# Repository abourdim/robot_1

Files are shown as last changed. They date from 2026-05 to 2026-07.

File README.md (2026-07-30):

# 🤖 esp32c3_super_mini_robot — ESP32-C3 RISC-V Robot

ESP32-C3 robot project — Arduino/PlatformIO firmware, browser-based flasher and monitor, audit dashboard, and a 9-theme Workshop-DIY web UI.

## 🌐 Live site

**[abourdim.github.io/esp32c3_super_mini_robot](https://abourdim.github.io/esp32c3_super_mini_robot/)** — auto-deployed from `01_software/01_app/02_web/` on every push.

### 📚 Guides — by audience

| Guide | For | What it covers |
|---|---|---|
| [`user-guide.html`](https://abourdim.github.io/esp32c3_super_mini_robot/user-guide.html) | 🦸 Kids · end users | Power on · pair phone · drive · light/sound meanings · troubleshooting · safety |
| [`build-guide.html`](https://abourdim.github.io/esp32c3_super_mini_robot/build-guide.html) | 🔧 Makers | BOM (~$30–45) · tools · wiring · step-by-step assembly · 3D parts · first flash |
| [`start-here.html`](https://abourdim.github.io/esp32c3_super_mini_robot/start-here.html) | 💻 Developers | Firmware narrative tour. 14 missions: layout, build, flash, debug. |
| [`learn.html`](https://abourdim.github.io/esp32c3_super_mini_robot/learn.html) | 🧠 Curious devs | Reference manual. Every `launch.sh` option · `platformio.ini` directive · RMT · partition table · addr2line · Web Serial. |
| [`hardware.html`](https://abourdim.github.io/esp32c3_super_mini_robot/hardware.html) | ⚡ Hardware hackers | Live PCB browser. 5-layer toggle · GPIO pin map · connector reference · links to KiCad source + gerbers + interactive BOM. |
| [`instructor.html`](https://abourdim.github.io/esp32c3_super_mini_robot/instructor.html) | 🧑‍🏫 Teachers | Prereqs · 90-min lesson plan · student FAQ · cheat sheet · reset checklist |

### 🛠️ Tools — runs in your browser

| Tool | What it does |
|---|---|
| [`flash.html`](https://abourdim.github.io/esp32c3_super_mini_robot/flash.html) | Click-to-flash via Web Serial (Chrome/Edge) |
| [`monitor.html`](https://abourdim.github.io/esp32c3_super_mini_robot/monitor.html) | Live serial monitor in the browser |
| [`audit.html`](https://abourdim.github.io/esp32c3_super_mini_robot/audit.html) | Bug tracker · severity dashboard · BUG-NNN forensics |
| [`index.html`](https://abourdim.github.io/esp32c3_super_mini_robot/) | Launcher landing page |

## 📁 Structure

```
esp32c3_super_mini_robot/
├── 01_software/
│   ├── 01_app/                  ⚙ main robot firmware (ESP32-C3 Arduino)
│   │   ├── 01_src/              source files (one .h/.cpp pair per system)
│   │   ├── 02_web/              browser tools (canonical Pages source)
│   │   ├── platformio.ini       build orders (pinned platform & libs)
│   │   └── launch.sh            interactive launcher menu
│   ├── 02_calibration/          calibration sketch
│   ├── 03_demo/                 demo project
│   ├── 05_bare_minimum/         minimal sketch
│   └── 4_wled/                  vendored WLED source
├── 02_hardware/                 (PCB design — TBD)
└── 03_3d/                       (3D-print files — TBD)
```

## 🚀 Quick start

```bash
cd 01_software/01_app
./launch.sh                    # interactive menu (option 0 = full setup)
./launch.sh flash              # one-shot: compile + upload + monitor
```

Everything else is documented inside the launcher menu and in the live site's [Start Here](https://abourdim.github.io/esp32c3_super_mini_robot/start-here.html) guide.

## 🎨 Themes

The web tools ship with **9 themes in 4 audience-mood groups**:

- 🔬 **Science** — `lab-light` · `lab-dark`
- 💻 **Hacker** — `terminal` · `solarized`
- 🤖 **Pro** — `robot` (default)
- 🦸 **Kids action** — `bot-pop` · `kapow` · `blastoff` · `dino`

Switch in **Settings (⚙️)** in any tool. Plus 3 languages (EN/FR/AR with RTL).

## 🐛 Known bugs

See [`audit.html`](https://abourdim.github.io/esp32c3_super_mini_robot/audit.html) for the live tracker. Headline incidents documented:
- **BUG-001** — RMT ISR recursion crash on ESP32-C3 (✅ fixed by pinning to ESP-IDF 5.1)
- **BUG-002** — Ctrl+C in MSYS2 monitor (🔍 open)
- **BUG-003** — Unpinned platform → non-reproducible builds (✅ fixed)
- **BUG-004** — RemoteXY "No PRO license" (🔍 open — UI exceeds free 5-var quota)
- **BUG-005** — Native USB CDC reset race during esptool upload (🔍 open)

## 📜 License

Vendored WLED is MIT — see `01_software/4_wled/WLED/LICENSE`. Project code: license TBD.

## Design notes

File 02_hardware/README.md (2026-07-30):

# 🔌 Hardware

KiCad source, PCB renders, BOMs, and gerbers for the Robot-01 board.

## Versions

| Version | Date | Status | Folder |
|---|---|---|---|
| **v3** | June–July 2025 | ✅ **Current — schematic source of truth** | [`v3/`](v3/) |
| v2 | May–June 2025 | 🔒 Archived | [`v2/`](v2/) |
| v1 | Aug 2025 (1st batch) | 🔒 Archived | [`v1/`](v1/) |

## Live browser

The current version is also rendered as a layered SVG viewer on the website:
**[abourdim.github.io/esp32c3_super_mini_robot/hardware.html](https://abourdim.github.io/esp32c3_super_mini_robot/hardware.html)** — toggle layers, zoom, link to source.

## v3 contents

```
v3/
├── 37_rich_light_move_v3.kicad_sch      ← schematic (S-expressions, text)
├── 37_rich_light_move_v3.kicad_pcb      ← PCB layout
├── 37_rich_light_move_v3.kicad_pro      ← KiCad project file
├── 37_rich_light_move_v3-F_Cu.svg       ← front copper render
├── 37_rich_light_move_v3-B_Cu.svg       ← back copper render
├── 37_rich_light_move_v3-F_Silkscreen.svg
├── 37_rich_light_move_v3-F_Courtyard.svg
├── 37_rich_light_move_v3-Edge_Cuts.svg
├── 00_lcsc/                             ← LCSC parts BOMs
├── bom/ibom.html                        ← interactive BOM (KiCad InteractiveHtmlBom)
└── production/                          ← gerbers + CSVs for fab
    ├── 37_richa_light_move_v3.zip       ← gerbers (send to PCBWay/JLCPCB)
    ├── bom.csv
    ├── designators.csv
    ├── netlist.ipc
    └── positions.csv
```

## Top-level BOM files

`bom_lcsc.xls`, `bom_jlcpcb2.xls`, `bom_assembly_jlcpcb_21062025.xls` — alternate BOM exports for different fab houses.

## Auto-backups (gitignored)

KiCad creates `*-backups/` folders with timestamped zips on every save.
These are **not tracked** — see project root `.gitignore`. Real source is in
the `.kicad_sch` / `.kicad_pcb` files themselves.

## Datasheet

`2410121311_S-S-SFN-1407PA7-6_C360603.pdf` — datasheet for one of the
LCSC parts used in the build (component lookup by C-number).

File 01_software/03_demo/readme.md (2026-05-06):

/c/Users/Win10/.platformio/packages/tool-esptoolpy/esptool.py --chip esp32c3 --port COM15  erase_flash

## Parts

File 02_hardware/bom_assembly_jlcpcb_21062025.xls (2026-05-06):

Comment | Designator | Footprint | JLCPCB Part #
1k | R1,R3,R8 | 0805 | C17513
4K7 | R4,R9 | 0805 | C17673
Conn_01x04_Pin | J6 | PinHeader_1x04_P2.54mm_Vertical | C2718488
AMS1117-5.0 | U4 | SOT-223-3_TabPin2 | C6187
100nF | C1,C2,C3,C4,C5,C6 | 0805 | C49678
TB6612FNG | U1 | SSOP-24_5.3x8.2mm_P0.65mm | C88224
SK12D07VG4 | U2 | SK12D07VG4 | C393937
blue | D8 | 0805 | C2293
led_tx1812cxa_5050 | D1,D2,D3,D4 | led_tx1812cxa_5050 | C784550
10K | R10,R11,R2,R5,R6,R7 | 0805 | C17414
green | D5 | 0805 | C2297
SW_Omron_B3FS | SW1 | SW_Push_1P1T_NO_6x6mm_H9.5mm | C5143662
Screw_Terminal_01x02 | J1,J11,J7,J8,J9 | TerminalBlock_Phoenix_MPT-0,5-2-2.54_1x02_P2.54mm_Horizontal | C2922597
green | D7,D6 | LED_D3.0mm | C85160
Conn_01x03_Pin | J2,J3,J4,J5 | PinHeader_1x03_P2.54mm_Vertical | C2937625
BUZZER | BZ2 | Buzzer_TDK_PS1240P02BT_D12.2mm_H6.5mm | C360603

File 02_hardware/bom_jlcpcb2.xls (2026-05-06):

Comment | Designator | Footprint | JLCPCB Part #
1k | R1,R13,R2,R3,R4 | 0805 | C17513
4K7 | R14,R7 | 0805 | C17673
AMS1117-5.0 | U3 | SOT-223-3_TabPin2 | C6187
100nF | C1,C2,C3,C4 | 0805 | C49678
SK12D07VG4 | U1 | SK12D07VG4 | C393937
led_tx1812cxa_5050 | D10,D11,D12,D9 | led_tx1812cxa_5050 | C784550
10K | R10,R11,R12,R5,R6,R8,R9 | 0805 | C17414
yellow | D3,D4 | 0805 | C2296
green | D5 | 0805 | C2297
SW_Omron_B3FS | SW1 | SW_Push_1P1T_NO_6x6mm_H9.5mm | C5143662
2N7002 | Q1,Q2 | SOT-23_Handsoldering | C8545
1N4007 | D1,D2 | D_SOD-123F | C2892681
Conn_01x03_Pin | J4,J5,J6,J7,J8,J9 | PinHeader_1x03_P2.54mm_Vertical | C2937625

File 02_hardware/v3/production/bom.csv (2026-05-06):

Designator | Footprint | Quantity | Value | LCSC Part #
BB1 | oled_128X64_no_holes | 1 | oled_128x32
BZ1 | buzz_8x14 | 1 | buzz_8x14
BZ2 | Buzzer_TDK_PS1240P02BT_D12.2mm_H6.5mm | 1 | BUZZER
C1, C2, C3, C4, C5, C6 | 0805 | 6 | 100nF
D1, D2, D3, D4 | led_tx1812cxa_5050 | 4 | led_tx1812cxa_5050
D5 | 0805 | 1 | green
D6 | LED_D3.0mm | 1 | green
D7 | LED_D3.0mm | 1 | blue
D8 | 0805 | 1 | blue
H1 | MountingHole_3.2mm_M3_Pad_Via | 1 | MountingHole
J1, J11, J7, J8, J9 | TerminalBlock_Phoenix_MPT-0,5-2-2.54_1x02_P2.54mm_Horizontal | 5 | Screw_Terminal_01x02
J10 | JST_PH_S2B-PH-K_1x02_P2.00mm_Horizontal | 1 | Conn_01x02_Pin
J2, J3, J4, J5 | PinHeader_1x03_P2.54mm_Vertical | 4 | Conn_01x03_Pin
J6 | PinHeader_1x04_P2.54mm_Vertical | 1 | Conn_01x04_Pin
JP1, JP2 | SolderJumper-2_P1.3mm_Open_TrianglePad1.0x1.5mm | 2 | SolderJumper_2_Open
R1, R3, R8 | 0805 | 3 | 1k
R10, R11, R2, R5, R6, R7 | 0805 | 6 | 10K
R4, R9 | 0805 | 2 | 4K7
SW1 | SW_Push_1P1T_NO_6x6mm_H9.5mm | 1 | SW_Omron_B3FS
U1 | SSOP-24_5.3x8.2mm_P0.65mm | 1 | TB6612FNG
U2 | SK12D07VG4 | 1 | SK12D07VG4
U3 | MODULE_ESP32-C3_SUPERMINI | 1 | ESP32-C3_SUPERMINI
U4 | SOT-223-3_TabPin2 | 1 | AMS1117-5.0

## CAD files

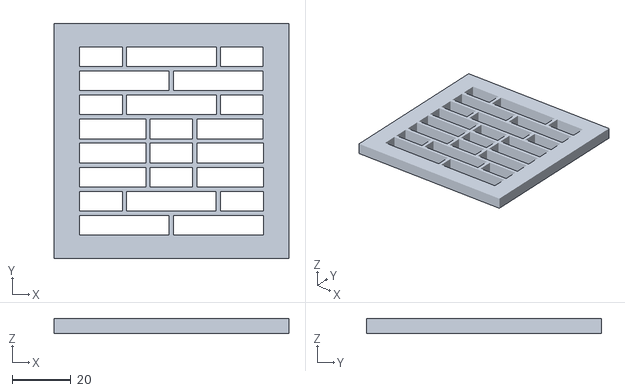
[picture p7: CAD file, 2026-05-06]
01_software/4_wled/WLED/usermods/word-clock-matrix/Word Clock Baffle.stl
80.0 x 80.0 x 5.00

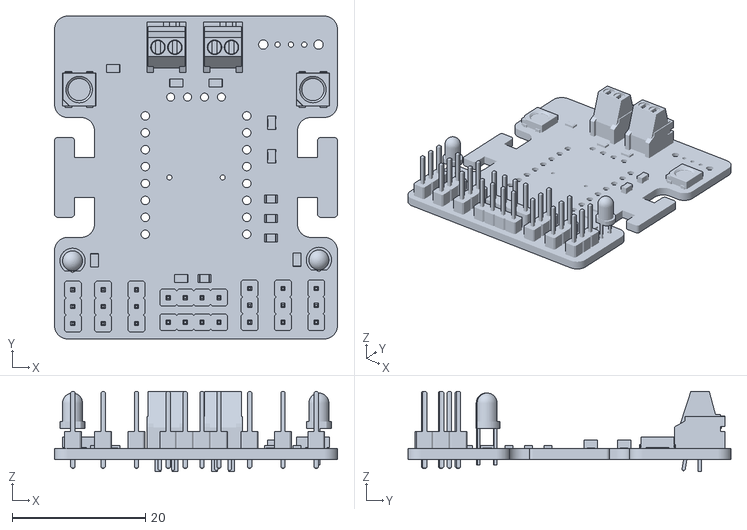
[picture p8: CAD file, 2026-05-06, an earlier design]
02_hardware/v1/1.stl
42.5 x 48.5 x 12.0

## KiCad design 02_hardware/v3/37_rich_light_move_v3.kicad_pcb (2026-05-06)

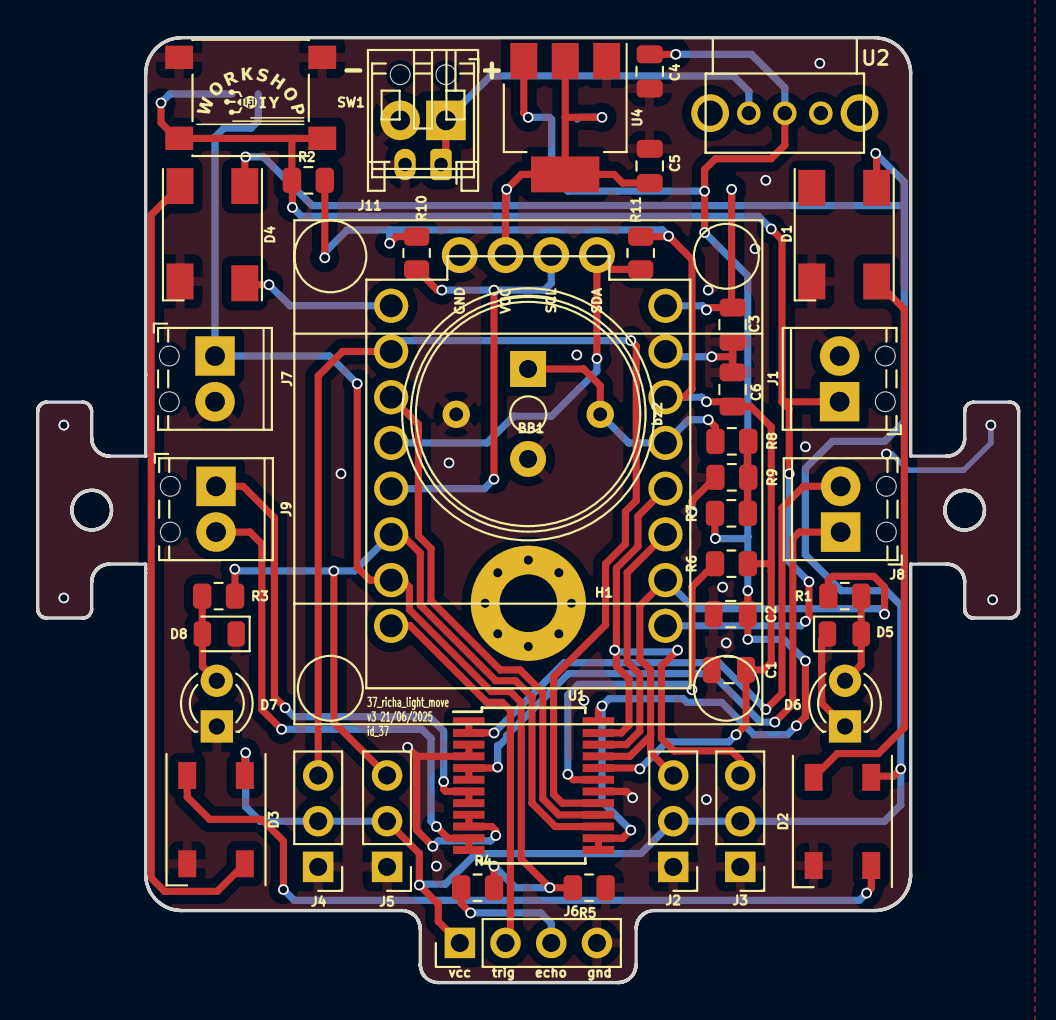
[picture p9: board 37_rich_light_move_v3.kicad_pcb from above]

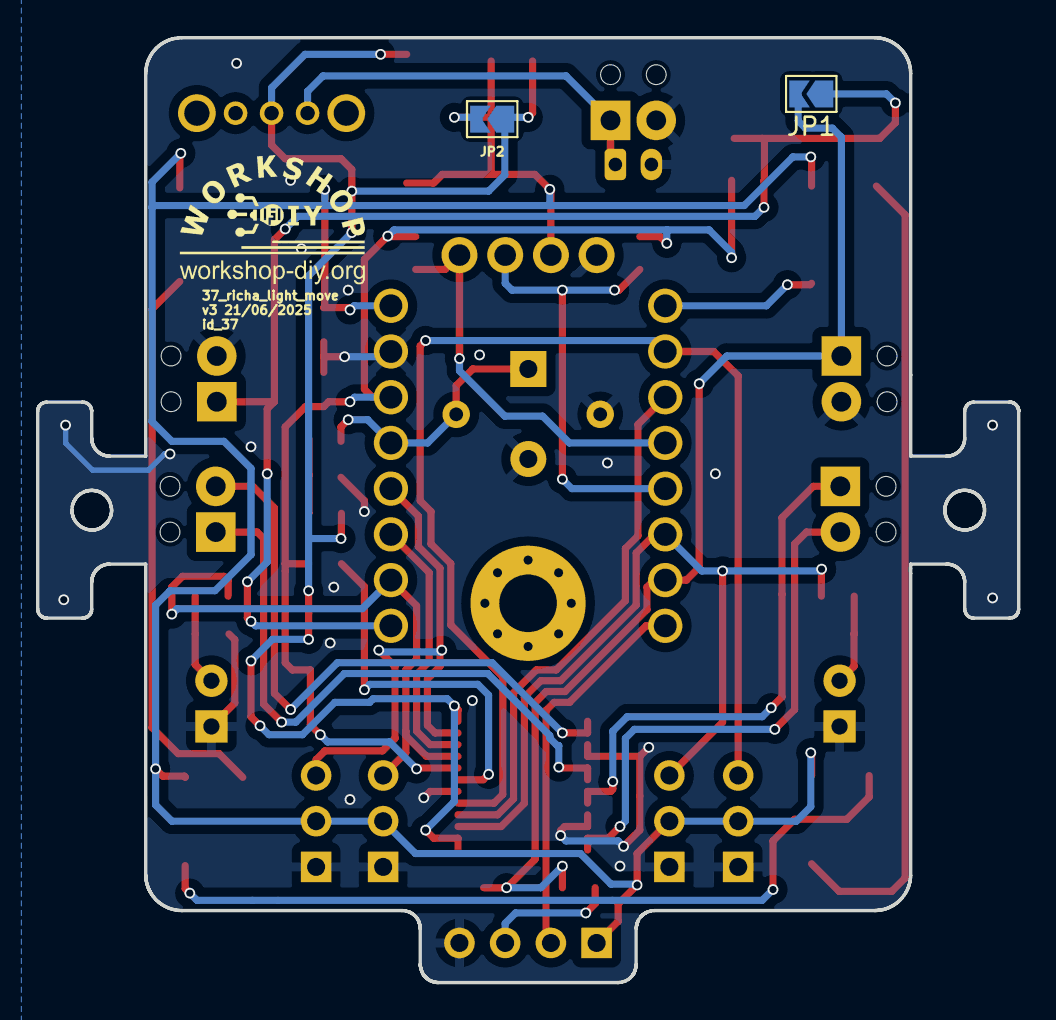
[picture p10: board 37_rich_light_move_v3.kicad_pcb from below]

Board: 2 copper layers, 54.5 x 52.5 mm, 47 parts (2 on the bottom side), 30 nets.

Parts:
BB1: oled_128x32; oled_128X64_no_holes
C1, C2, C3, C4, C5, C6: 100nF; C_0805_2012Metric
D1, D2, D3, D4: led_tx1812cxa_5050
D5: green; LED_0805_2012Metric
D6: green; LED_D3.0mm
D7: blue; LED_D3.0mm
D8: blue; LED_0805_2012Metric
H1: MountingHole; MountingHole_3.2mm_M3_Pad_Via
J1, J7, J8, J9, J11: Screw_Terminal_01x02; TerminalBlock_Phoenix_MPT-0,5-2-2.54_1x02_P2.54mm_Horizontal
J2, J3, J4, J5: Conn_01x03_Pin; PinHeader_1x03_P2.54mm_Vertical
J6: Conn_01x04_Pin; PinHeader_1x04_P2.54mm_Vertical
J10: Conn_01x02_Pin; JST_PH_S2B-PH-K_1x02_P2.00mm_Horizontal
JP1, JP2: SolderJumper_2_Open; SolderJumper-2_P1.3mm_Open_TrianglePad1.0x1.5mm
R1, R3, R8: 1k; R_0805_2012Metric
R2, R6, R7: 10k; R_0805_2012Metric
R4, R9: 4K7; R_0805_2012Metric
R5, R10, R11: 10K; R_0805_2012Metric
SW1: SW_Omron_B3FS; SW_Push_1P1T_NO_6x6mm_H9.5mm
U1: TB6612FNG; SSOP-24_5.3x8.2mm_P0.65mm
U2: SK12D07VG4
U3: ESP32-C3_SUPERMINI; MODULE_ESP32-C3_SUPERMINI
U4: AMS1117-5.0; SOT-223-3_TabPin2
bz1: buzz_8x14
bz2: BUZZER; Buzzer_TDK_PS1240P02BT_D12.2mm_H6.5mm

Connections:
3V3: C1.1, C6.1, R2.1, R6.1, R10.1, R11.1, U1.20 (VCC), U3.3.3 (3V3)
5V: BB1.2 (VCC), C3.1, C5.1, D1.1 (VDD), D2.1 (VDD), D3.1 (VDD), D4.1 (VDD), J2.2, J3.2, J4.2, J5.2, J6.1, JP2.2 (B), U3.5V, U4.2 (VO)
GND: BB1.1 (GND), C1.2, C2.2, C3.2, C4.2, C5.2, C6.2, D1.3 (GND), D2.3 (GND), D3.3 (GND), D4.3 (GND), D5.1 (K), D6.1 (K), D7.1 (K), D8.1 (K), J1.2, J2.1, J3.1, J4.1, J5.1, J6.4, J7.2, J10.2, J11.2, R5.2, R9.2, SW1.2, U1.3 (PGND1), U1.4 (PGND1), U1.9 (PGND2), U1.10 (PGND2), U1.18 (GND), U3.G (GND), U4.1 (GND), bz1.1, bz2.2 (GND)
unnamed: D1.4 (DIN), D2.2 (DOUT)
unnamed: D2.4 (DIN), D3.2 (DOUT)
unnamed: D3.4 (DIN), D4.2 (DOUT)
unnamed: D5.2 (A), D6.2 (A), R1.2
unnamed: D7.2 (A), D8.2 (A), R3.2
unnamed: J6.3, R4.1
unnamed: J8.1, U1.5 (AO2), U1.6 (AO2)
unnamed: J8.2, U1.1 (AO1), U1.2 (AO1)
unnamed: J9.1, U1.7 (BO2), U1.8 (BO2)
unnamed: J9.2, U1.11 (BO1), U1.12 (BO1)
unnamed: R7.2, R8.1, R9.1
unnamed: R6.2, U1.19 (STBY)
VCC: C2.1, C4.1, JP2.1 (A), R7.1, U1.13 (VM2), U1.14 (VM3), U1.24 (VM1), U2.COM, U4.3 (VI)
VDDA: J10.1, J11.1, U2.2
gpio_00: J1.1, JP1.1 (A), R2.2, SW1.1, U3.0 (GPIO0)
gpio_01: J2.3, R1.1, U1.21 (AIN1), U3.1 (GPIO1)
gpio_02: U1.22 (AIN2), U3.2 (GPIO2)
gpio_03: J3.3, U1.23 (PWMA), U3.3 (GPIO3)
gpio_04: R8.2, U3.4 (GPIO4), bz1.2, bz2.1 (POS)
gpio_05: D4.4 (DIN), U3.5 (GPIO5)
gpio_06: J4.3, U1.17 (BIN1), U3.6 (GPIO6)
gpio_07: U1.16 (BIN2), U3.7 (GPIO7)
gpio_08: BB1.4 (SDA), R11.2, U3.8 (GPIO8)
gpio_09: BB1.3 (SCL), R10.2, U3.9 (GPIO9)
gpio_10: J5.3, R3.1, U1.15 (PWMB), U3.10 (GPIO10)
gpio_20: J7.1, JP1.2 (B), R4.2, R5.1, U3.20 (GPIO20)
gpio_21: J6.2, U3.21 (GPIO21)

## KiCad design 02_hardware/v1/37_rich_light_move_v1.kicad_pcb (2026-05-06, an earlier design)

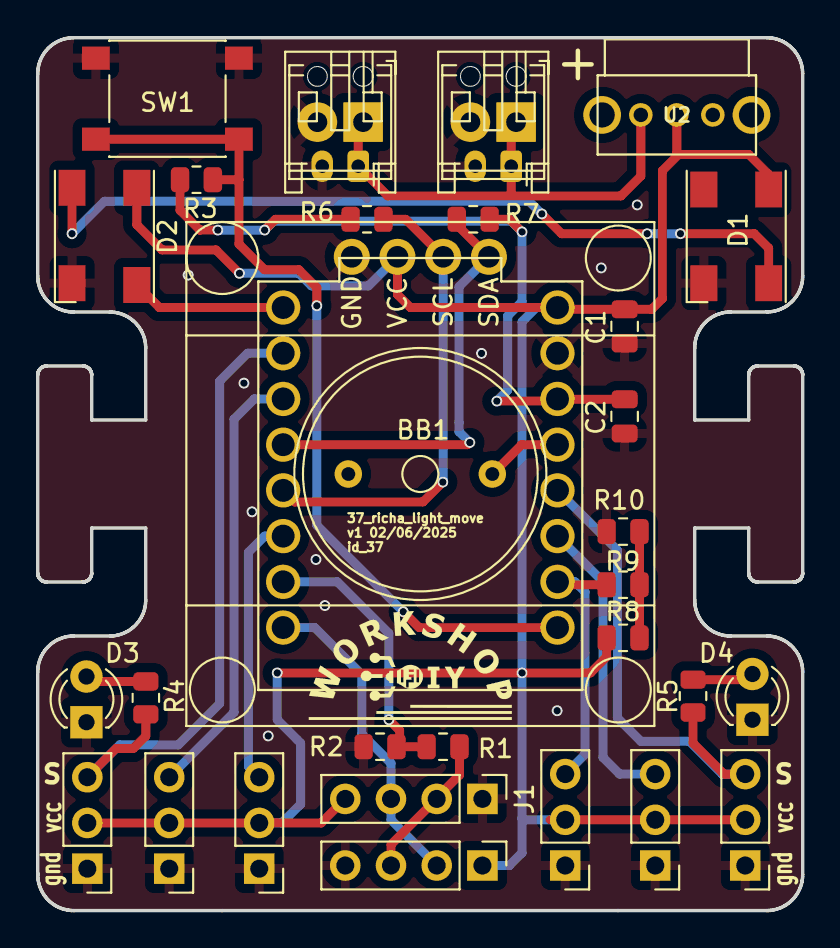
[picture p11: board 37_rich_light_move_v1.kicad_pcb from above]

Board: 2 copper layers, 42.5 x 48.5 mm, 33 parts (0 on the bottom side), 22 nets.

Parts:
BB1: oled_128x32; oled_128X64_no_holes
C1, C2: 100nF; C_0805_2012Metric
D1, D2: led_tx1812cxa_5050
D3, D4: yellow; LED_D3.0mm
J1, J2: Conn_01x04_Pin; PinHeader_1x04_P2.54mm_Vertical
J3, J4, J5, J6, J7, J8: Conn_01x03_Pin; PinHeader_1x03_P2.54mm_Vertical
J9, J10: Conn_01x02_Pin; JST_PH_S2B-PH-K_1x02_P2.00mm_Horizontal
J11, J12: Screw_Terminal_01x02; TerminalBlock_Phoenix_MPT-0,5-2-2.54_1x02_P2.54mm_Horizontal
R1: 4K7; R_0805_2012Metric
R2, R6, R7: 10K; R_0805_2012Metric
R3, R8, R10: 10k; R_0805_2012Metric
R4, R5, R9: 1k; R_0805_2012Metric
SW1: SW_Omron_B3FS; SW_Push_1P1T_NO_6x6mm_H9.5mm
U1: ESP32-C3_SUPERMINI; MODULE_ESP32-C3_SUPERMINI
U2: SK12D07VG4
bz1: buzz_8x14

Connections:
3V3: C2.1, R3.1, R6.1, R7.1, U1.3.3 (3V3)
GND: BB1.1 (GND), C1.2, C2.2, D1.3 (GND), D2.3 (GND), D3.1 (K), D4.1 (K), J1.1, J2.4, J3.1, J4.1, J5.1, J6.1, J7.1, J8.1, J9.2, J10.2, J11.2, J12.2, R2.2, R10.2, SW1.2, U1.G (GND), bz1.1
unnamed: D1.4 (DIN), D2.2 (DOUT)
unnamed: D3.2 (A), R4.2
unnamed: D4.2 (A), R5.2
unnamed: J1.2, J2.3, R1.1
unnamed: R8.2, R9.1, R10.1
VCC: BB1.2 (VCC), C1.1, D1.1 (VDD), D2.1 (VDD), J1.4, J2.1, J3.2, J4.2, J5.2, J6.2, J7.2, J8.2, R8.1, U1.5V, U2.COM
VDDA: J9.1, J10.1, J11.1, J12.1, U2.2
gpio_00: R3.2, SW1.1, U1.0 (GPIO0)
gpio_01: J7.3, R9.2, U1.1 (GPIO1)
gpio_02: J3.3, U1.2 (GPIO2)
gpio_03: J8.3, R5.1, U1.3 (GPIO3)
gpio_04: U1.4 (GPIO4), bz1.2
gpio_05: D2.4 (DIN), U1.5 (GPIO5)
gpio_06: J4.3, R4.1, U1.6 (GPIO6)
gpio_07: J5.3, U1.7 (GPIO7)
gpio_08: BB1.4 (SDA), R7.2, U1.8 (GPIO8)
gpio_09: BB1.3 (SCL), R6.2, U1.9 (GPIO9)
gpio_10: J6.3, U1.10 (GPIO10)
gpio_20: R1.2, R2.1, U1.20 (GPIO20)
gpio_21: J1.3, J2.2, U1.21 (GPIO21)

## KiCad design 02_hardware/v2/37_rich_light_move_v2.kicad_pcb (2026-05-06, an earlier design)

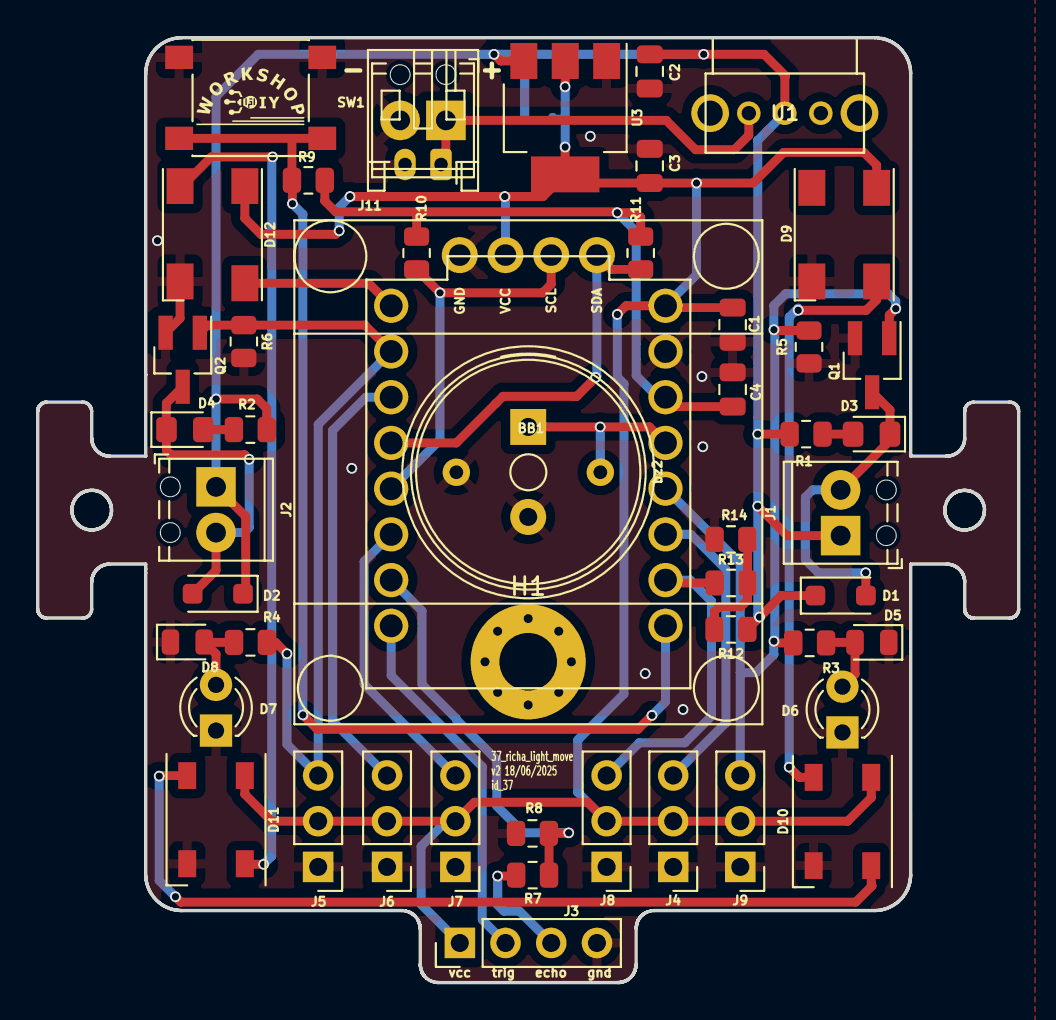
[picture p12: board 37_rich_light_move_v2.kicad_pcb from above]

Board: 2 copper layers, 54.5 x 52.5 mm, 52 parts (1 on the bottom side), 29 nets.

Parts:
BB1: oled_128x32; oled_128X64_no_holes
C1, C2, C3, C4: 100nF; C_0805_2012Metric
D1, D2: 1N4007; D_SOD-123F
D3, D4: yellow; LED_0805_2012Metric_Pad1.15x1.40mm_HandSolder
D5: green; LED_0805_2012Metric
D6: green; LED_D3.0mm
D7: blue; LED_D3.0mm
D8: blue; LED_0805_2012Metric
D9, D10, D11, D12: led_tx1812cxa_5050
H1: MountingHole; MountingHole_3.2mm_M3_Pad_Via
J1, J2, J11: Screw_Terminal_01x02; TerminalBlock_Phoenix_MPT-0,5-2-2.54_1x02_P2.54mm_Horizontal
J3: Conn_01x04_Pin; PinHeader_1x04_P2.54mm_Vertical
J4, J5, J6, J7, J8, J9: Conn_01x03_Pin; PinHeader_1x03_P2.54mm_Vertical
J10: Conn_01x02_Pin; JST_PH_S2B-PH-K_1x02_P2.00mm_Horizontal
JP1: SolderJumper_2_Open; SolderJumper-2_P1.3mm_Open_TrianglePad1.0x1.5mm
Q1, Q2: 2N7002; SOT-23_Handsoldering
R1, R2, R3, R4, R13: 1k; R_0805_2012Metric
R5, R6, R9, R12: 10k; R_0805_2012Metric
R7, R14: 4K7; R_0805_2012Metric
R8, R10, R11: 10K; R_0805_2012Metric
SW1: SW_Omron_B3FS; SW_Push_1P1T_NO_6x6mm_H9.5mm
U1: SK12D07VG4
U2: ESP32-C3_SUPERMINI; MODULE_ESP32-C3_SUPERMINI
U3: AMS1117-5.0; SOT-223-3_TabPin2
bz1: buzz_8x14
bz2: BUZZER; Buzzer_TDK_PS1240P02BT_D12.2mm_H6.5mm

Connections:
3V3: C4.1, R9.1, R10.1, R11.1, U2.3.3 (3V3)
5V: BB1.2 (VCC), C1.1, C3.1, D9.1 (VDD), D10.1 (VDD), D11.1 (VDD), D12.1 (VDD), J3.1, J4.2, J5.2, J6.2, J7.2, J8.2, J9.2, JP1.2 (B), U2.5V, U3.2 (VO)
GND: BB1.1 (GND), C1.2, C2.2, C3.2, C4.2, D5.1 (K), D6.1 (K), D7.1 (K), D8.1 (K), D9.3 (GND), D10.3 (GND), D11.3 (GND), D12.3 (GND), J3.4, J4.1, J5.1, J6.1, J7.1, J8.1, J9.1, J10.2, J11.2, Q1.2 (S), Q2.2 (S), R5.2, R6.2, R8.2, R14.2, SW1.2, U2.G (GND), U3.1 (GND), bz1.1, bz2.2 (GND)
unnamed: D1.2 (A), D3.1 (K), J1.2, Q1.3 (D)
unnamed: D2.2 (A), D4.1 (K), J2.2, Q2.3 (D)
unnamed: D3.2 (A), R1.2
unnamed: D4.2 (A), R2.2
unnamed: D5.2 (A), D6.2 (A), R3.2
unnamed: D7.2 (A), D8.2 (A), R4.2
unnamed: D10.4 (DIN), D11.2 (DOUT)
unnamed: D9.4 (DIN), D10.2 (DOUT)
unnamed: D11.4 (DIN), D12.2 (DOUT)
unnamed: J3.3, R7.1
unnamed: R12.2, R13.1, R14.1
VCC: C2.1, D1.1 (K), D2.1 (K), J1.1, J2.1, JP1.1 (A), R1.1, R2.1, R12.1, U1.COM, U3.3 (VI)
VDDA: J10.1, J11.1, U1.2
gpio_00: R9.2, SW1.1, U2.0 (GPIO0)
gpio_01: J8.3, R13.2, U2.1 (GPIO1)
gpio_02: J4.3, U2.2 (GPIO2)
gpio_03: J9.3, Q1.1 (G), R3.1, R5.1, U2.3 (GPIO3)
gpio_04: U2.4 (GPIO4), bz1.2, bz2.1 (POS)
gpio_05: D12.4 (DIN), U2.5 (GPIO5)
gpio_06: J5.3, Q2.1 (G), R4.1, R6.1, U2.6 (GPIO6)
gpio_07: J6.3, U2.7 (GPIO7)
gpio_08: BB1.4 (SDA), R11.2, U2.8 (GPIO8)
gpio_09: BB1.3 (SCL), R10.2, U2.9 (GPIO9)
gpio_10: J7.3, U2.10 (GPIO10)
gpio_20: R7.2, R8.1, U2.20 (GPIO20)
gpio_21: J3.2, U2.21 (GPIO21)

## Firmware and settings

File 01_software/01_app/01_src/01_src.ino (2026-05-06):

///////////////////////////////////////////////
//        RemoteXY include library          //
//////////////////////////////////////////////

#include "01_includes.h"

Adafruit_SSD1306 display(SCREEN_WIDTH, SCREEN_HEIGHT, &Wire, OLED_RESET);

// ===========================================================================
void setup() {
// ===========================================================================

  // Serial for debugging
  #ifdef DEF_DERIAL_DEBUG
  Serial.begin(115200);
  #endif

  // Initialize RemoteXY
  //RemoteXY_Init();

  remotexy_init();
  
  // Allocate timer for ESP32 PWM
  ESP32PWM::allocateTimer(0);
  
  // Attach servos to their pins
  servoLeft.attach(CONFIG_PIN_SERVO_LEFT);
  servoRight.attach(CONFIG_PIN_SERVO_RIGHT);
  
  // Stop both servos initially
  stopServos();

    // Set custom I2C pins
  Wire.begin(CONFIG_PIN_OLED_SDA, CONFIG_PIN_OLED_SCL);

  // Initialize OLED
  if (!display.begin(SSD1306_SWITCHCAPVCC, 0x3C)) {
    #ifdef DEF_DERIAL_DEBUG
    Serial.println(F("SSD1306 allocation failed"));
    #endif
    // for (;;);
  }

  display.clearDisplay();
  display.setTextColor(SSD1306_WHITE);

  leds_init();
  oled_init();

  ultrasonic_init();

  g_ultrasonic_distance_cm=0;
  g_elapsed_time_startup_millis = millis();  // Record start time

  neopixels_init();

  buzzer_init();
  buzzer_beep();

  neopixels_all_blink(CRGB::Green, 3, 20);

  remotexy_set_sound_01(REMOTEXY_SOUND_POWER_ON);  
  
  button_init();

    // Add battery pin setup
  pinMode(CONFIG_PIN_BATTERY_LEVEL, INPUT);  
   
  event_connection_state_flag_bo = remotexy_get_connect_flag();  // Set initial state

  g_battery_raw_adc = 0;
  g_battery_voltage = 0;
  g_battery_percentage = 0;

  g_previous_millis_u32 = 0;

}

// ===========================================================================
void loop() {
// ===========================================================================

  remotexy_handler();

  tasks_connect();
  tasks_buttons();
  tasks_joysticks();
  tasks_elapsed_time();  
  tasks_rmotexy_sound();
  
  if (events_get_timeout_flag() == EVENTS_TIMEOUT_OCCURED) {  
    
    ultrasonic_get_distance();
    tasks_battery();
    
    tasks_remotexy();
    oled_update();
    leds_update();
    
  }

  events_reset_connect_flag();

  if (events_get_timeout_flag() == EVENTS_TIMEOUT_OCCURED) {
    events_reset_timeout_flag();
  }

  //neopixels_star();

  neopixels_waving_french_flag();

  //neopixels_KnightRiderRedEyewithTail();
  //neopixels_KnightRiderRedEyewithTail2();
  //neopixels_duel_eye();

  //neopixels_animate();
}

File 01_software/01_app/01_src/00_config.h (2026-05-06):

#ifndef __DEF_INCLUDE_CONFIG_H__
#define __DEF_INCLUDE_CONFIG_H__


#define CONFIG_REMOTEXY_BLUETOOTH_NAME "diy_app_b3"

#define DEF_DERIAL_DEBUG



// --------------------------------------
// button
#define CONFIG_PIN_BUTTON 0

// --------------------------------------
// buzzer
#define CONFIG_PIN_BUZZER 4
#define CONFIG_BUZZER_FREQ 4000

// battery level
#define CONFIG_PIN_BATTERY_LEVEL 4

#define BATTERY_MIN_V 3.3  // Minimum battery voltage (adjust according to your battery)
//#define BATTERY_MAX_V 4.2  // Maximum battery voltage (adjust according to your battery)
#define BATTERY_MAX_V 4.5  // Maximum battery voltage (adjust according to your battery)

// --------------------------------------
// neopixel

#define CONFIG_NEOPIXELS_MAX_LEDS 256      // Max supported (array size)

#if 1
  #define CONFIG_PIN_NEOPIXEL 5
  #define CONFIG_NEOPIXELS_NB_LEDS 4       // Active LED count
#else
  #define CONFIG_PIN_NEOPIXEL 10            // external strip
  #define CONFIG_NEOPIXELS_NB_LEDS 16       // Active LED count
#endif

#define CONFIG_NEOPIXELS_BRIGHTNESS 15       // Brightness (0-255)



// --------------------------------------
// I2C pins
#define CONFIG_PIN_OLED_SDA 8
#define CONFIG_PIN_OLED_SCL 9

// --------------------------------------
// Ultrasonic sensor pins
#define CONFIG_PIN_SR04_TRIG 21
#define CONFIG_PIN_SR04_ECHO 20

// --------------------------------------
// Servo configuration

#define CONFIG_SERVO_SPEED_STOP_LEFT    90
#define CONFIG_SERVO_SPEED_STOP_RIGHT   90

#define CONFIG_SERVO_SPEED_STOP_LEFT_OFFSET    5
#define CONFIG_SERVO_SPEED_STOP_RIGHT_OFFSET    5

#define CONFIG_PIN_SERVO_LEFT  6   // GPIO 6 for left servo
#define CONFIG_PIN_SERVO_RIGHT 3   // GPIO 3 for right servo

// #define CONFIG_PIN_SERVO_LEFT  7   // GPIO 6 for left servo
// #define CONFIG_PIN_SERVO_RIGHT 2   // GPIO 3 for right servo

// #define CONFIG_PIN_SERVO_LEFT  10   // GPIO 6 for left servo
// #define CONFIG_PIN_SERVO_RIGHT 1   // GPIO 3 for right servo

#define CONFIG_PIN_LED_RED 10   //
#define CONFIG_PIN_LED_GREEN 1   //

// #define LED_PIN_1 2
// #define LED_PIN_2 6

// OLED config
#define SCREEN_WIDTH 128
#define SCREEN_HEIGHT 64
#define OLED_RESET    -1  // Reset pin not used

#endif // __DEF_INCLUDE_CONFIG_H__

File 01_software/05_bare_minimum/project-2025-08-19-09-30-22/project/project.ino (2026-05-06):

/*
   -- 001_robot_lite_app_v1.0 --
   
   To compile this code using RemoteXY library 3.1.13 or later version 
   download by link http://remotexy.com/en/library/
   To connect using RemoteXY mobile app by link http://remotexy.com/en/download/                   
     - for ANDROID 4.15.01 or later version;
     - for iOS 1.12.1 or later version;
    
   To interact with the GUI, please refer to the manual: 
   https://remotexy.com/ru/help/code/interaction/

   This source code was automatically generated by the RemoteXY editor and 
   is an example for the RemoteXY library. 
   Licensed under the MIT License. See the LICENSE file in the RemoteXY library
   root (https://github.com/RemoteXY/RemoteXY-Arduino-library) for full license 
   details.    
*/

//////////////////////////////////////////////
//        RemoteXY include library          //
//////////////////////////////////////////////

// you can enable debug logging to Serial at 115200
//#define REMOTEXY__DEBUGLOG    

// RemoteXY select connection mode and include library 
#define REMOTEXY_MODE__ESP32CORE_BLE

#include <BLEDevice.h>

// RemoteXY connection settings 
#define REMOTEXY_BLUETOOTH_NAME "01_ble"


#include <RemoteXY.h>

// RemoteXY GUI configuration  
#pragma pack(push, 1)  
uint8_t RemoteXY_CONF[] =   // 176 bytes
  { 255,3,0,15,0,169,0,19,0,0,0,0,179,2,130,200,108,200,1,1,
  5,0,5,32,128,71,71,23,109,60,60,21,137,178,179,68,1,52,128,62,
  3,41,33,40,51,180,50,133,94,68,105,115,116,97,110,99,101,0,83,112,
  101,101,100,0,66,97,116,116,101,114,121,0,72,66,22,37,37,2,3,24,
  24,108,166,140,178,180,0,0,0,0,0,0,200,66,0,0,0,0,137,0,
  0,0,0,0,0,240,65,79,0,0,248,65,0,0,112,66,50,0,0,116,
  66,0,0,200,66,1,1,1,128,20,40,253,24,24,9,179,31,119,111,114,
  107,115,104,111,112,45,100,105,121,46,111,114,103,32,58,32,65,80,80,95,
  86,49,46,48,0,69,17,27,19,19,2,175,20,20,0,150 };
  
// this structure defines all the variables and events of your control interface 
struct {

    // input variables
  int8_t joystick_01_x; // from -100 to 100
  int8_t joystick_01_y; // from -100 to 100
  uint8_t button_01; // =1 if button pressed, else =0

    // output variables
  float onlineGraph_01_distance;
  float onlineGraph_02_speed;
  float onlineGraph_03_battery;
  int8_t circularBar_01; // from 0 to 100
  int16_t sound_01; // =0 no sound, else ID of sound, =1001 for example, look sound list in app

    // other variable
  uint8_t connect_flag;  // =1 if wire connected, else =0

} RemoteXY;   
#pragma pack(pop)
 
/////////////////////////////////////////////
//           END RemoteXY include          //
/////////////////////////////////////////////



void setup() 
{
  RemoteXY_Init (); 
  
  
  // TODO you setup code
  
}

void loop() 
{ 
  RemoteXY_Handler ();
  
  
  // TODO you loop code
  // use the RemoteXY structure for data transfer
  // do not call delay(), use instead RemoteXY_delay() 


}

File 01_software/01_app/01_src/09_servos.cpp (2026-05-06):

#include "01_includes.h"


// ===========================================================================
void moveServos(int32_t leftSpeed, int32_t rightSpeed) {
// ===========================================================================
  leftSpeed = constrain(leftSpeed, 0, 180);
  rightSpeed = constrain(rightSpeed, 0, 180);
  
  servoLeft.write(leftSpeed);
  servoRight.write(rightSpeed);

  g_speed_s1 = leftSpeed;
  g_speed_s2 = rightSpeed;
  
  // For debugging
  #ifdef DEF_DERIAL_DEBUG
  // Serial.printf("Left: %d, Right: %d\n", leftSpeed, rightSpeed);
  #endif
}

// ===========================================================================
void stopServos() {
// ===========================================================================
  moveServos(CONFIG_SERVO_SPEED_STOP_LEFT, CONFIG_SERVO_SPEED_STOP_RIGHT);
}

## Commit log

2026-05-06 Initial commit — robot_1
    - 01_app: ESP32-C3 RISC-V robot firmware (Arduino/PlatformIO) +
    02_web tools (start-here, flash, monitor, audit) with shared
    Workshop-DIY shell, 9 themes, 3 languages.
    - 02_calibration, 03_demo, 05_bare_minimum: helper sketches.
    - 4_wled: vendored WLED source.
    - 02_hardware, 03_3d: placeholder dirs.
    [AutoCubeMap.xlsx, IR_Remote_Codes.xlsx, WLED_ESP32-wrover_4MB.csv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]
2026-05-06 Remove geolocation prompt from night-mode auto-detect
    The Workshop-DIY template's initNightMode() was calling
    navigator.geolocation.getCurrentPosition() to compute precise
    local sunset time. That triggered a 'Allow location?' permission
    popup on every page load — annoying and pointless for a robot
    launcher. Replaced with a plain getHours() check: 21:00–06:00
    still auto-applies the lab-dark theme (only if the user hasn't
    picked one), no permission prompt.
2026-05-06 Fix splash overlay — selector mismatch between markup and CSS
    The splash markup uses id="splash" but the CSS targeted .splash
    (class). Selector never matched, so position:fixed; inset:0;
    z-index:10000 never applied — the splash rendered as a flex
    sibling next to the app instead of as a full-screen overlay.
    Changed .splash → #splash and .splash.hidden → #splash.hidden
    in wdiy-template.css. Inner classes (.splash-inner, .splash-logo,
    .splash-title, .splash-sub, .splash-hint) stay as-is.
2026-05-06 Audit: log BUG-006..009 — web-tools forensics
    BUG-006 (2026-05-06 07:24) Geolocation popup on every page load
    — initNightMode() called navigator.geolocation.getCurrentPosition().
    Fix: dropped the geolocation block, kept clock-only night detect.
    BUG-007 (2026-05-06 07:27) Splash overlay broken — selector mismatch
    — markup id="splash", CSS .splash class — never matched.
    Fix: .splash → #splash in wdiy-template.css.
    BUG-008 (2026-05-06 06:40) Pixel pet duplicates in footer
    — initPixelPet() not idempotent.
    Fix: early return if #pixelPet already exists.
    BUG-009 (2026-05-06 07:00) Light-theme polish (3 sub-issues bundled)
    — muddy cards (rgba(0,0,0,.22) bg), invi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
2026-05-06 Add three audience-targeted guides + Robot-37 → Robot-01 rename
    NEW GUIDES (~1500 lines of content total):
    - user-guide.html 🦸 kids/end users · 9 sections · default theme bot-pop
    · power · pair · drive · LEDs · sounds · senses · troubleshoot · safety
    - build-guide.html 🔧 makers · 6 sections · default theme lab-light
    · BOM (~$30-45) · tools · wiring SVG · pin map · 10-step assembly · 3D parts · first flash
    - instructor.html 🧑‍🏫 teachers · 6 sections · default theme lab-dark
    · prereqs · 90-min lesson plan · FAQ · cheat sheet · reset checklist · curriculu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
2026-05-06 Add learn.html — technical reference manual
    NEW PAGE: 02_web/learn.html ~770 lines default theme: lab-dark
    5 top-level sections, all with deep-dive cards:
    § 1 🚀 Launcher anatomy — every option of launch.sh (0–19)
    · grouped by toolchain / deploy / cyberspace / misc / git ops
    · each option: what · underlying CLI · failure modes · cross-link
    · CLI shortcut callouts (./launch.sh compile · upload · flash · serve)
    § 2 ⚙️ platformio.ini decoded — every directive in our config
    · plus useful directives we don't (yet) use: monitor_filters,
    upload_protocol = esp-builtin, board_build.partitions, etc.
    · pinning philosophy: hard-pin plat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
2026-05-06 Add hardware page + reconcile docs with v3 schematic
    NEW PAGE: 02_web/hardware.html ~610 lines
    - Layered PCB SVG viewer (Edge_Cuts / F_Cu / F_Silkscreen / F_Courtyard / B_Cu)
    - Toggle buttons with mix-blend-mode multiply for clean layer overlays
    - GPIO pin map straight from the v3 schematic (color-grouped: motor / I2C / input / aux)
    - 11-connector reference (J1-J11, BB1) with what-plugs-where notes
    - Key ICs table (ESP32-C3 SuperMini, TB6612FNG, AMS1117, slide switch, B3F button)
    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
    [01_bom_lcsc.xls, 1.stl, 37_rich_light_move_v1.kicad_pcb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]
2026-05-06 Reference RNT 'Getting Started ESP32-C3 Super Mini' + board quirks
    Pulled board-specific facts from
    https://randomnerdtutorials.com/getting-started-esp32-c3-super-mini/
    (the canonical reference for this dev board) and folded them into our docs.
    learn.html § 3 — added 'ESP32-C3 SuperMini board-specific quirks'
    subsection (7-row table) covering:
    - Onboard LED on GPIO 8 is ACTIVE LOW (blue)
    - Antenna defect on some batches (C3 capacitor ~1.5mm vs spec ~3.3mm)
    - Breadboard metal kills Wi-Fi range (raise board 15+mm)
    - Power LED steals ~500uA in deep sleep (10x datasheet)
    - USB CDC On Boot must be enabled in Arduino IDE
    - Deep-sleep upload trap + BOOT/RESET workaround
    - Default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
2026-05-06 Fix GPIO 3 / GPIO 5 / JP2 description after schematic re-read
    GPIO 3 — wasn't 'PWMA OR external via JP2'. It's PWMA always; J3 just
    taps the same signal. JP2 is a power-rail selector for J3's V+ pin
    (VCC direct vs 5V regulated), per the 2025-06-21 schematic note —
    NOT a routing jumper. Confused myself by reading the JP2 footprint
    without checking the designer's annotation.
    GPIO 5 — was marked '— unused —'. Actually drives 4 onboard
    TX1812 5050 addressable RGB LEDs (D1→D2→D3→D4 daisy chain). This is
    the 'rich_light' part of the project name. NeoPixels are NOT an
    optional add-on via J3 — they're already on the board.
    BOM correction in build-guide.html: 'WS2812B (optional, v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
2026-05-06 Add v3 3D render as hero image + bundle PNG/JPG via Pages workflow
    - 02_hardware/v3/37_rich_light_move_v3.png: 3D render of the v3 PCB
    (top view, ~290 KB). Confirms component layout: WORKSHOP DIY logo,
    buzzer in center, 4 NeoPixels at corners, motor screw terminals on
    the sides, ESP32-C3 module, and the 'vcc trig echo gnd' HC-SR04
    silkscreen on J6.
    - hardware.html: figure.pcb-hero block at the top, between the version
    banner and the layered SVG viewer. img loads from
    hardware/v3/37_rich_light_move_v3.png with a caption overlay.
    - pages.yml workflow: stages *.png and *.jpg from 02_hardware/v3/
    into the deploy artifact, alongside the SVG layers. Path filter
    expanded to trigge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
2026-05-06 Add schematic SVG embed + B_Silkscreen layer to hardware.html
    NEW ARTIFACTS in 02_hardware/v3/:
    - 37_rich_light_move_v3-schematic.svg (1.6 MB) — full schematic, text-searchable
    - 37_rich_light_move_v3-B_Silkscreen.svg (340 KB) — back silk layer (new)
    - F_Cu / F_Silkscreen / Edge_Cuts re-exported (May 2026 timestamps)
    hardware.html:
    - New § 1 'Schematic — full design' collapsible above the PCB browser:
    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
2026-05-06 audit: log BUG-011 + BUG-012 from esp32c3-lab v0.1.0 build
    BUG-011 (2026-05-06 15:09) Web Bluetooth picker shows no devices
    Root cause: NimBLE relocates the 128-bit NUS UUID into the
    scan-response packet (because esp32c3-lab name + UUID overflows
    the 31-byte advertisement budget). Chrome's requestDevice()
    filter only reads the primary advertisement.
    Fix: filter list accepts services [NUS_SERVICE] OR namePrefix
    'esp32c3' OR exact name 'esp32c3-lab'.
    BUG-012 (2026-05-06 17:30) esp32c3-lab firmware build trio
    Three sequential failures hit while compiling the new firmware
    sketch from scratch:
    a) build_flags_extra (invented directive — only emits warning)
    b) Nothing t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
2026-05-06 audit BUG-012: corrected forensic for Serial-symbol issue
    Phase-1 fix (dropping user-code Serial.* calls) only solved half the
    problem. The framework's own HardwareSerial.cpp also fails to compile
    because serialEventRun() calls Serial.available() — ARDUINO_USB_CDC_ON_BOOT=1
    on the c3-devkitm-1 profile leaves Serial in macro limbo for framework
    translation units in arduino-esp32 2.0.16.
    Phase-2 fix: remove -DARDUINO_USB_CDC_ON_BOOT=1 entirely. Default
    (CDC off) → Serial = HardwareSerial(0) via SOC_RX0 path. Framework
    compiles. User code doesn't reference Serial. esptool upload still
    works via the chip's built-in USB JTAG/Serial.
    Audit entry rewritten with: framework-vs-user-code distinc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
